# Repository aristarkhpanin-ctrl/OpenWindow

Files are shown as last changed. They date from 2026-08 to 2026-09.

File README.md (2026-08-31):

# OpenWindow — Zigbee-привод открывания окна на проветривание

Проект превращает 3D-печатный реечный привод из папки `pok016/`
в полноценное Zigbee-устройство: окно открывается и закрывается
из Home Assistant, по расписанию, по CO₂ или по датчику дождя.

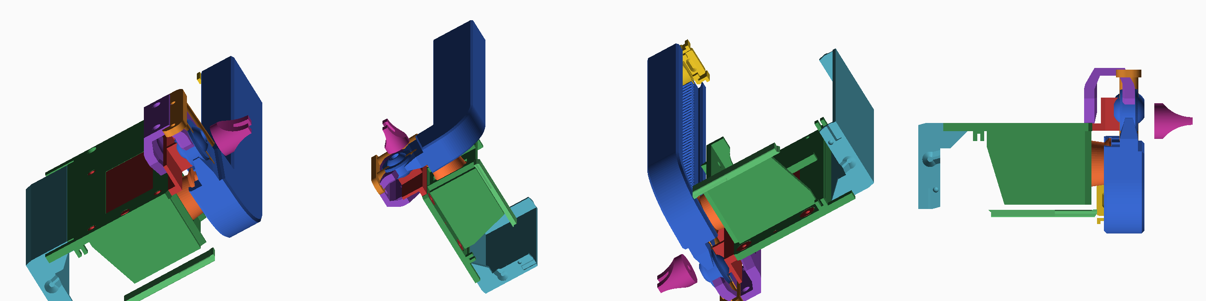
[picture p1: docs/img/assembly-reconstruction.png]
Реконструкция сборки


## Что получится

- Устройство видно в сети как стандартная **штора (Window Covering)** —
  Home Assistant, Zigbee2MQTT и deCONZ понимают его без кастомных описаний.
- Команды: открыть / закрыть / стоп / **позиция в процентах**.
- **Защита от защемления** по току мотора: упёрлись — остановились и отъехали.
- Позиция переживает отключение питания.
- Ручное управление кнопкой на плате.

## С чего начать

Читайте по порядку — документы идут в том порядке, в котором делается работа:

| Документ | О чём |
|---|---|
| [0. С чего начать](docs/00-roadmap.md) | **читайте первым**: порядок работ, чекпоинты, что заказывать сейчас |
| [1. Разбор макетов](docs/01-mechanics.md) | что за механизм в `pok016/`, все обмеры, чего в наборе не хватает |
| [2. Что купить](docs/02-bom.md) | список компонентов, выбор мотора, расчёт момента |
| [3. Печать и сборка](docs/03-print-and-assembly.md) | параметры печати, сборка узлов, установка на окно |
| [4. Электроника](docs/04-electronics.md) | схема, распиновка, монтаж, настройка защиты |
| [5. Прошивка](docs/05-firmware.md) | установка Arduino IDE с нуля, заливка, калибровка |
| [6. Умный дом](docs/06-integration.md) | сопряжение, ZHA/Z2M, готовые автоматизации |

## Коротко о железе

| | |
|---|---|
| Контроллер | ESP32-C6 (Zigbee 3.0 + Wi-Fi + BLE) |
| Драйвер | DRV8871 |
| Мотор | червячный мотор-редуктор 12 В, 20 об/мин, вал ⌀6 мм с лыской |
| Датчик тока | INA219 |
| Питание | 12 В / 3 А |
| Ход | 100 мм, полный цикл ~5 с |
| Бюджет | ≈ 4 000 ₽ вместе с мотором и печатью |

## Главное, что нужно знать до начала

1. **В наборе нет ведущей шестерни.** Нужна отдельная, металлическая:
   модуль 1, z = 18, ширина ≥ 9 мм, посадка ⌀6 мм с лыской. Подробности —
   в [разборе макетов](docs/01-mechanics.md), §1.3.
2. **Редуктор должен быть червячным.** Он самотормозящий, иначе ветер
   и вес створки будут продавливать рейку назад.
3. **Печатайте PETG, не PLA.** Привод стоит у окна и летом греется
   выше температуры размягчения PLA.
4. **Марка мотора из STL не восстанавливается.** Известен посадочный
   интерфейс (4×M3 сеткой 18 × 33 мм, вал ⌀6 с лыской); в
   [BOM](docs/02-bom.md) есть чек-лист проверки перед покупкой.

## Структура репозитория

```
pok016/                            исходные STL (как были загружены)
docs/                              документация
firmware/zigbee_window_opener/     скетч Arduino + config.h
tools/                             скрипты обмера и рендера STL
```

## Инструменты обмера

Все размеры в документации получены скриптами из `tools/` — их можно
перезапустить и проверить:

```bash
pip install numpy
python3 tools/stlinfo.py pok016       # габариты и объёмы
python3 tools/holes.py   pok016       # цилиндрические отверстия и их координаты
python3 tools/render.py  pok016 out/  # изометрии деталей в PNG
```

## Безопасность

Устройство двигает створку с усилием под 200 Н. Не собирайте его
без защиты по току, проверьте траекторию створки и оставьте
возможность отсоединить рейку от окна без инструмента.
Подробно — в [разделе 4](docs/04-electronics.md), §3.5.

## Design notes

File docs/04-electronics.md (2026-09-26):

# 3. Электроника: схема и монтаж

## 3.1. Структура

```
     ┌──────────────┐
     │ БП 12 В / 3 А│
     └──────┬───────┘
            │ 12 В
     ┌──────┴────────┬─────────────────┐
     │               │                 │
┌────┴─────┐   ┌─────┴──────┐   ┌──────┴──────┐
│ MP1584EN │   │  INA219    │   │  DRV8871    │
│ 12В → 5В │   │ (в разрыв  │   │  VM         │
└────┬─────┘   │  плюса     │   │             │
     │ 5 В     │  мотора)   │   │  OUT1 OUT2  │
     │         └─────┬──────┘   └───┬─────┬───┘
┌────┴──────────┐    │              │     │
│  ESP32-C6     │    │          ┌───┴─────┴───┐
│               │◄───┘ I²C      │ Мотор 12 В  │
│ GPIO2  ───────┼───────────────► IN1         │
│ GPIO3  ───────┼───────────────► IN2         │
│ GPIO6  SDA    │               └─────────────┘
│ GPIO7  SCL    │
│ GPIO18 ◄──────┼─── концевик «закрыто»  ─── GND
│ GPIO19 ◄──────┼─── концевик «открыто»  ─── GND
└───────────────┘
```

## 3.2. Таблица соединений

### Питание

| Откуда | Куда | Провод |
|---|---|---|
| БП 12 В «+» | предохранитель 2 А → шина 12 В | 0,5 мм² |
| Шина 12 В | MP1584 `IN+` | 0,5 мм² |
| Шина 12 В | INA219 `VIN+` | 0,5 мм² |
| INA219 `VIN−` | DRV8871 `VM` | 0,5 мм² |
| БП «−» | общая земля GND | 0,5 мм² |
| MP1584 `OUT+` (**5,0 В**) | ESP32-C6 `5V` | 0,2 мм² |
| MP1584 `OUT−` | GND | 0,2 мм² |

> ❗ **MP1584 нужно настроить ДО подключения платы.** Подайте на него 12 В,
> подкрутите подстроечник, добейтесь на выходе **5,0 В по мультиметру**,
> и только потом подключайте ESP32. На модуле «из коробки» может быть
> и 12 В на выходе — это мгновенно убьёт плату.

### Сигналы

| ESP32-C6 | Куда | Примечание |
|---|---|---|
| GPIO2 | DRV8871 `IN1` | ШИМ 20 кГц |
| GPIO3 | DRV8871 `IN2` | ШИМ 20 кГц |
| GPIO6 | INA219 `SDA` | подтяжки есть на модуле |
| GPIO7 | INA219 `SCL` | |
| 3V3 | INA219 `VCC` | датчик питается от 3,3 В |
| GPIO18 | концевик «закрыто», контакт **COM** | второй контакт (**NO**) → GND |
| GPIO19 | концевик «открыто», контакт **COM** | второй контакт (**NO**) → GND |
| GND | общая земля | обязательно одна точка |

Концевики подключаются **нормально-разомкнутыми на замыкание в GND**.
Внутренняя подтяжка включена в прошивке (`INPUT_PULLUP`), внешние резисторы
не нужны. Логика: нажат → LOW → «доехали».

### Мотор

| DRV8871 | Куда |
|---|---|
| `VM` | 12 В (через INA219) |
| `GND` | общая земля |
| `OUT1` | провод мотора A |
| `OUT2` | провод мотора B |

Полярность мотора на этом этапе неважна — если окно поедет не в ту сторону,
поменяйте `#define MOTOR_INVERT 0` на `1` в `config.h`. Это надёжнее,
чем перепаивать.

## 3.3. Обязательные мелочи, о которых легко забыть

1. **Электролит 470 мкФ / 25 В** — прямо на клеммах `VM`/`GND` драйвера.
   Пусковой ток мотора проседает питание, и без этого конденсатора
   ESP32 будет перезагружаться в момент старта. Это самая частая проблема
   в подобных проектах.
2. **0,1 мкФ** на питание INA219 и на 3,3 В ESP32.
3. **Скрутите провода мотора в косичку** — они излучают помехи прямо
   в антенну Zigbee, которая находится в 3 см.
4. **Общая земля одной точкой.** Не соединяйте GND «гирляндой» через модули.
5. Провода мотора и питания — **не ближе 10 мм к антенне** ESP32-C6
   (это торец платы с зигзагом дорожки; его нельзя закрывать металлом).

## 3.4. Настройка порога защиты от защемления

Порог `CURRENT_STALL_A` в `config.h` подбирается **по факту**, на собранном
приводе. Порядок:

1. В скетче поставьте `#define DEBUG_CURRENT 1`, прошейте плату,
   откройте Serial Monitor на 115200. Ток начнёт печататься 5 раз в секунду.
2. Прогоните окно из края в край и запишите **рабочий** ток — обычно 0,3–0,7 А.
3. Придержите створку рукой и посмотрите ток **упора** — обычно 1,5–2,5 А.
4. Поставьте порог **посередине**: например, рабочий 0,6 А, упор 2,0 А → `1.20f`.
5. Верните `#define DEBUG_CURRENT 0`.

Слишком низкий порог → привод будет останавливаться на ровном месте.
Слишком высокий → защемление сработает поздно. Лучше начать с низкого
и поднимать.

## 3.5. Безопасность

Это устройство двигает тяжёлую створку с усилием под 200 Н. Отнеситесь всерьёз:

- **Защита по току обязательна.** Не собирайте без INA219 «на время» —
  временное имеет свойство оставаться навсегда.
- **Не ставьте на окно в детской**, если рядом нет присмотра.
- **Проверьте траекторию створки** — на пути не должно быть штор, цветов, рам.
- **Предохранитель 2 А** на входе — не пропускайте.
- Держите **ручной режим**: рейка должна отсоединяться от створки штифтом M4
  без инструмента, чтобы окно можно было открыть руками при отказе электроники.
- Если корпус нагревается выше ~50 °C при работе — что-то не так, ищите причину.

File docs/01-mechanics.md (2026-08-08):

# 1. Разбор макетов из `pok016/`

Всё ниже — результат прямого обмера STL-файлов (скрипты лежат в `tools/`).
Исходного CAD и инструкции в репозитории нет, поэтому сборка восстановлена
по координатам: детали лежат в одной системе координат, то есть они уже
расставлены «как в сборке», а не по центру нуля.

Реконструкция сборки

## 1.1. Что это за механизм

Это **реечный привод (rack & pinion)** для откидного окна:
электромотор через шестерню двигает зубчатую рейку, рейка упирается в створку
и отжимает её на проветривание. Обратный ход — закрывает.

Ключевой момент, который определяет весь выбор электроники: **рейка Г-образная**.
Прямой зубчатый участок идёт вдоль корпуса, а внизу переходит в изогнутый «крюк»
с проушиной — она шарнирно крепится к створке. За счёт изгиба привод получается
компактным, а створка при этом отходит по дуге.

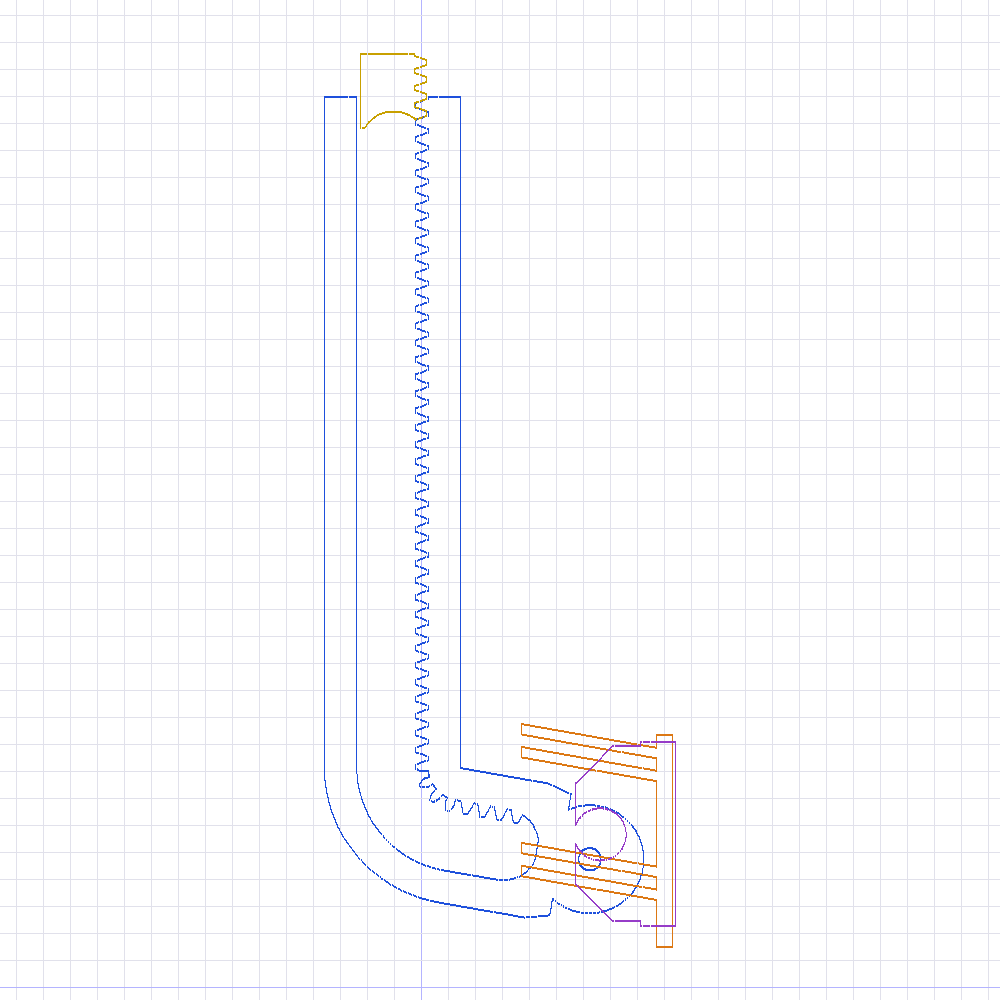
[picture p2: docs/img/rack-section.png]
Сечение рейки


## 1.2. Таблица деталей

| Файл | Габарит, мм | Объём | Назначение |
|---|---|---|---|
| `pok16-openerRack.stl` | 15,8 × 59,2 × 152,0 | 38,8 см³ | Зубчатая рейка с крюком и проушиной |
| `pok16-openerCover.stl` | 70,2 × 37,4 × 97,0 | 34,6 см³ | Корпус целиком (мотор + электроника) |
| `pok16-openerMotoBase.stl` | 58,5 × 32,2 × 93,5 | 16,5 см³ | Рама с площадкой мотора, крепится к раме окна |
| `pok16-openerGuide1.stl` | 55,8 × 13,0 × 67,2 | 10,7 см³ | Г-образный кронштейн-направляющая |
| `pok16-openerLid.stl` | 20,5 × 33,8 × 84,0 | 8,7 см³ | Крышка отсека электроники |
| `pok16-openerFixer.stl` | 20,0 × 22,0 × 34,0 | 6,2 см³ | Кронштейн на створку (ответная часть) |
| `pok16-openerGuide2.stl` | 10,0 × 28,0 × 42,3 | 2,5 см³ | Прижимная направляющая рейки |
| `pok16-openerEndstop.stl` | 14,7 × 19,0 × 13,7 | 1,5 см³ | Ограничитель хода вверху |
| `pok16-openerFixerNut.stl` | 15,0 × 14,0 × 14,0 | 1,2 см³ | Ответная гайка/подложка к Fixer |
| `pok16-openerMotoFix.stl` | ⌀20,5 × 12,8 | 1,05 см³ | Коническая втулка-фиксатор вала |
| `pok016-MotoFix.stl` | ⌀20,5 × 12,8 | 1,05 см³ | То же самое, повёрнуто «под печать» |
| `pok16-openerMasker.stl` | 42,7 × 3,1 × 7,7 | 0,86 см³ | Накладка-заглушка |
| `pok16-openerGearSpacer.stl` | ⌀12 × 4,0 | 0,29 см³ | Дистанционная шайба на вал мотора |
| `pok16-openerMotoFixSuport.stl` | ⌀17,8 × 2,0 | 0,22 см³ | Опорная шайба под втулку |
| `pok16-openerOffTool.stl` | 18,0 × 0,4 × 23,5 | 0,11 см³ | Тонкий «ключ» для ручного расцепления |
| `pok16-openerMotoNut.stl` | ⌀7,3 × 1,2 | 0,04 см³ | Шаблон гнезда под гайку M4 |
| `pok16-openerLid-Insert.stl` | 21,2 × 31,6 × 78,9 | — | Вспомогательный «негатив» отсека электроники |
| `pok16-openerLid-Inset-Open.stl` | 26,1 × 31,6 × 78,9 | — | То же, вариант с проёмом |

Последние две — не печатаемые детали, а булевы заготовки из CAD.
Печатать их не нужно, но они очень полезны: `Lid-Insert` — это ровно тот объём,
который остаётся свободным под плату и провода.

## 1.3. Точные размеры, которые важны для сборки

### Зубчатое зацепление

| Параметр | Значение | Как измерено |
|---|---|---|
| Шаг зубьев | **3,142 мм** | расстояние между вершинами зубьев по STL |
| Модуль | **m = 1** | шаг / π = 3,142 / 3,1416 |
| Высота зуба | 2,25 мм | = 2,25 · m, стандартная пропорция |
| Ширина зуба (венца) | **9,0 мм** | рейка по X: 43,1…52,1 |
| Длина зубчатого участка | ~112 мм | прямая часть по Z: 45…157 |
| Ось шестерни | 9,25 мм от делительной линии рейки | центр отверстия ⌀21 минус линия зуба |

Отсюда шестерня: **модуль 1, z = 18, делительный ⌀18 мм, ширина ≥ 9 мм**.
Межосевое по модели 9,25 мм при теоретических 9,0 — заложено 0,25 мм зазора,
это нормальный люфт для FDM-печати.

> ⚠️ **Шестерни в наборе нет.** Из 18 файлов ни один не является ведущей
> шестернёй. Её нужно либо купить (латунная/стальная m1 z18 с посадкой ⌀6 мм
> под лыску), либо сгенерировать самому — я бы советовал купить металлическую:
> это самая нагруженная деталь привода.

### Вал мотора

`GearSpacer` — шайба ⌀12 × 4 мм с отверстием **⌀6 мм с лыской на 2,24 мм от оси**
(то есть «под ключ» 5,24 мм). Это прямо говорит:

> **вал мотора — ⌀6 мм, D-образный (со срезом).**

### Площадка мотора

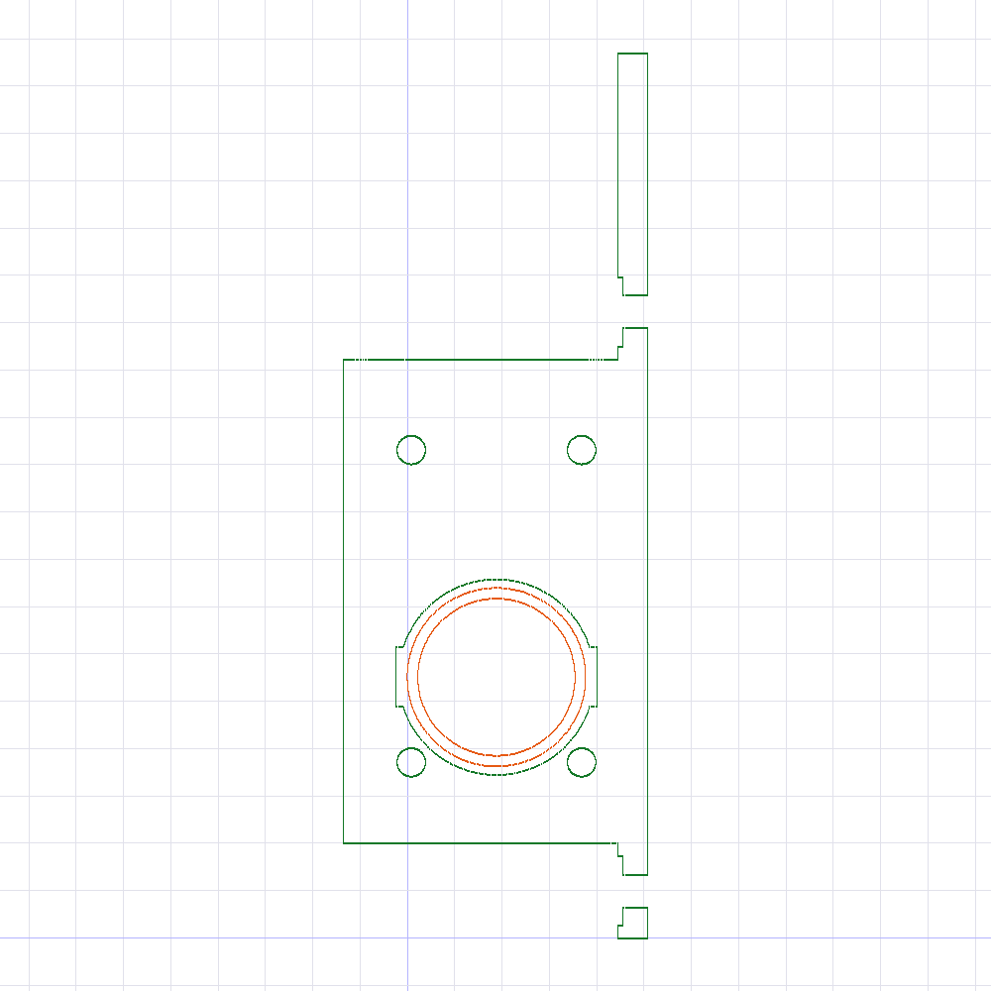
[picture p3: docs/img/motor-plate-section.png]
Сечение площадки мотора


- пластина толщиной 2,4 мм;
- **4 отверстия ⌀3,0 мм (под M3) прямоугольником 18 × 33 мм**;
- центральное отверстие ⌀≈21 мм под выходную втулку/бобышку редуктора;
- ось вала смещена: она на 9 мм ниже центра прямоугольника отверстий.

Это несимметричное расположение — «отпечаток» конкретного мотора.
Смотрите `docs/02-bom.md`, там процедура проверки перед покупкой.

### Крепление к раме окна

Общий для `MotoBase`, `Cover` и `Guide1` шаблон: **4 самореза, сетка 31,5 × 61,2 мм**.
- `MotoBase`: сквозные ⌀3,8 мм с зенковкой ⌀7,5 мм;
- `Guide1`: направляющие ⌀2,5 мм (кондуктор для сверления);
- `Cover`: бобышки ⌀10 мм, сквозь которые проходят те же саморезы.

Под саморез 4 × 30…40 мм по ПВХ-профилю.

### Крепление к створке

`Fixer` + `FixerNut`: два отверстия M3 (⌀3,3 с зенковкой ⌀6,2/6,5) и ось ⌀4,0 мм.
Проушина рейки — ⌀3,79 мм. Значит шарнир — **штифт или винт M4**.

## 1.4. Отсек электроники — сколько у нас места

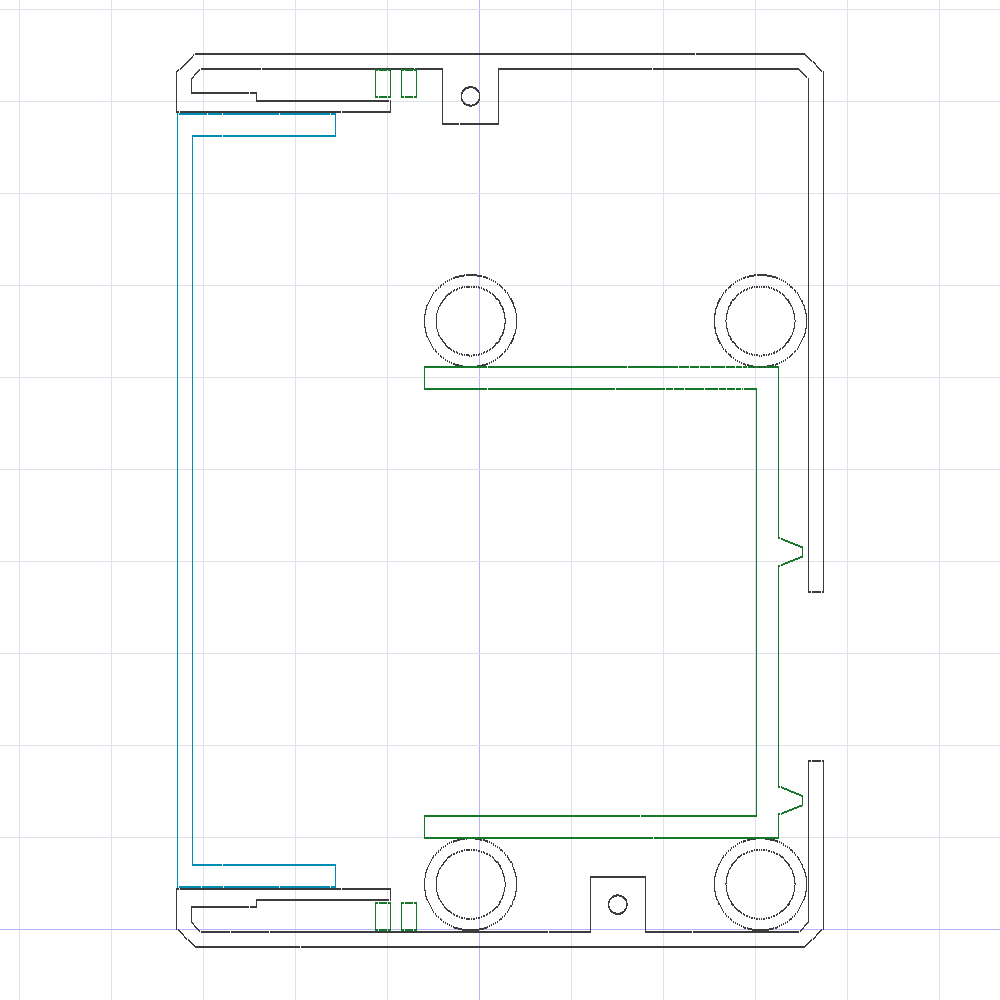
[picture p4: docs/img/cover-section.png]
Сечение корпуса


Свободный объём под крышкой `Lid` (по «негативу» `Lid-Insert`):

> **21,2 × 31,6 × 78,9 мм**

Это ~53 см³. Немало, но узко: 21 мм — жёсткое ограничение по толщине.
Практический вывод для выбора компонентов:

- **влезает**: ESP32-C6 SuperMini (23 × 18 мм), драйвер DRV8871 (20 × 20 мм),
  понижающий модуль MP1584 (22 × 17 мм) — все три «столбиком» по высоте;
- **влезает с натягом**: ESP32-C6-DevKitC-1 (52 × 25,5 мм) — по ширине проходит,
  но USB-разъём придётся выводить наружу;
- **не влезает**: аккумулятор 18650 вместе с платами. Либо банка, либо электроника.

Поэтому базовый вариант в этом проекте — **питание от внешнего блока 12 В**,
а не автономный. Подробности и обоснование — в `docs/04-electronics.md`.

## 1.5. Что осталось неизвестным

Честно перечисляю, чего из STL получить нельзя:

1. **Точная модель мотора.** Известен посадочный интерфейс (4×M3 18×33 мм,
   вал ⌀6 с лыской, бобышка ⌀21), но не марка. Проверочная процедура — в BOM.
2. **Точное число зубьев шестерни** — 18 по расчёту, но допускаю 19 при другом
   расположении оси. Проверяется примеркой: рейка должна ходить без закусывания.
3. **Порядок сборки** от автора. Реконструкция по координатам даёт взаимное
   положение деталей, но не последовательность операций.

## 1.6. Как повторить обмер

```bash
pip install numpy
python3 tools/stlinfo.py pok016            # габариты и объёмы всех деталей
python3 tools/holes.py   pok016            # все цилиндрические отверстия
python3 tools/render.py  pok016 out/       # изометрии каждой детали в PNG
```

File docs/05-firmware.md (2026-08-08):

# 4. Прошивка: от нуля до работающего устройства

Раздел рассчитан на то, что вы **никогда не держали в руках Arduino**.
Каждый шаг — буквальный.

## 4.1. Устанавливаем среду (20 минут)

### Шаг 1. Arduino IDE

Скачайте **Arduino IDE 2.x** с <https://www.arduino.cc/en/software> и установите.

### Шаг 2. Добавляем поддержку ESP32

1. `File` → `Preferences`.
2. В поле **Additional boards manager URLs** вставьте:
   ```
   https://espressif.github.io/arduino-esp32/package_esp32_index.json
   ```
3. `OK`.
4. Слева откройте **Boards Manager** (иконка платы), найдите **esp32 by Espressif Systems**.
5. Установите версию **3.1.0 или новее**. Это важно: Zigbee-библиотека
   появилась именно в 3.1.0. Установка займёт несколько минут — пакет большой.

### Шаг 3. Выбираем плату и режим

`Tools` → и выставьте:

| Параметр | Значение |
|---|---|
| Board | **ESP32C6 Dev Module** |
| **Zigbee mode** | **Zigbee ZCZR (coordinator/router)** |
| **Partition Scheme** | **Zigbee ZCZR 4MB with spiffs** |
| USB CDC On Boot | **Enabled** |
| Erase All Flash Before Sketch Upload | **Enabled** (только в первый раз!) |
| Port | появится после подключения платы по USB |

> Если пункта **Zigbee mode** нет — у вас старая версия ядра, вернитесь к шагу 2.
> Если не выставить Partition Scheme, прошивка соберётся, но Zigbee-стек
> не стартует: ему нужен отдельный раздел под сетевые ключи.

### Шаг 4. Открываем скетч

`File` → `Open` → выберите
`firmware/zigbee_window_opener/zigbee_window_opener.ino`.
Файл `config.h` подтянется автоматически и появится второй вкладкой.

## 4.2. Первая прошивка — на столе, без мотора

**Не подключайте мотор к первой прошивке.** Сначала убедимся, что
устройство входит в сеть.

1. Подключите ESP32-C6 к компьютеру по USB-C.
2. Нажмите **Upload** (стрелка вправо).
3. Если не прошивается — зажмите **BOOT**, коротко нажмите **RESET**,
   отпустите BOOT, повторите Upload.
4. Откройте `Tools` → **Serial Monitor**, скорость **115200**.

Вы должны увидеть:

```
=== OpenWindow — Zigbee window opener ===
[INA219] НЕ найден — защита по току отключена
[NVS] полный ход 9000 мс, позиция 100%
[ZB] запуск стека…
[ZB] подключение к сети....
```

Точки будут идти, пока устройство не вступит в сеть — это нормально.
Переходите к `docs/06-integration.md`, добавьте устройство в сеть,
и точки сменятся на `готово`.

## 4.3. Что делает прошивка

### Модель устройства

Устройство объявляет себя как **Window Covering** (кластер ZCL `0x0102`,
тип `AWNING`). Это даёт «бесплатно»:

- команды `Open`, `Close`, `Stop`, `Go to Lift Percentage`;
- атрибут текущей позиции, который координатор опрашивает и показывает;
- готовую сущность `cover.*` в Home Assistant с ползунком.

> **Про проценты.** В стандарте Zigbee `0 % = открыто`, `100 % = закрыто`.
> В Home Assistant у штор наоборот. Пересчёт делает координатор, вам
> ничего править не нужно — просто не пугайтесь, увидев в логах «100 %»
> у закрытого окна.

### Как считается позиция

Энкодера нет, поэтому позиция считается **по времени**:

1. При калибровке привод едет до упора «закрыто», потом до упора «открыто»
   и засекает длительность полного хода → `travelMs`.
2. `travelMs` сохраняется в NVS (переживает перезагрузку и отключение питания).
3. Во время движения позиция интегрируется по времени.
4. **Приезд в крайние положения обнуляет накопленную ошибку** — концевик
   важнее расчёта. Поэтому дрейф не накапливается: каждое полное
   открытие/закрытие «сбрасывает» счётчик.

Это классический подход для приводов штор, точность — единицы процентов.
Если нужна точность лучше — ставьте мотор с энкодером (см. `docs/02-bom.md`).

### Защита от защемления

Каждые 5 мс читается ток мотора через INA219. Если ток держится выше
`CURRENT_STALL_A` дольше `STALL_CONFIRM_MS` (250 мс):

1. мотор останавливается;
2. **отъезжает назад** на `BACKOFF_MS` (700 мс), освобождая зажатое;
3. устройство переходит в состояние `ST_FAULT`, светодиод краснеет;
4. позиция пересчитывается и отправляется координатору.

Первые `INRUSH_IGNORE_MS` (600 мс) после старта ток игнорируется —
пусковой бросок в 2–3 раза выше рабочего и иначе давал бы ложные срабатывания.

### Плавный пуск и торможение

Функция `rampedDuty()` разгоняет ШИМ за 350 мс и снижает его на подходе
к цели. Это заметно продлевает жизнь пластиковой рейке: удар зубьев
на полном моменте — главная причина их срезания.

## 4.4. Калибровка

Обязательна после сборки механики.

1. Убедитесь, что створка свободна и на пути ничего нет.
2. **Зажмите кнопку BOOT на 3–10 секунд**, отпустите.
3. Привод поедет закрываться до упора, потом откроется до упора.
4. В Serial Monitor появится:
   ```
   [CAL] полный ход = 6420 мс, сохранено
   ```
5. Всё, значение записано навсегда (до следующей калибровки).

### Все функции кнопки BOOT

| Нажатие | Действие |
|---|---|
| Короткое (< 3 с) | открыть, если закрыто; закрыть, если открыто; стоп во время движения |
| 3–10 с | калибровка |
| Дольше 10 с | сброс к заводским, выход из Zigbee-сети |

### Светодиод

| Цвет | Значение |
|---|---|
| Мигает жёлтым | ищет сеть |
| Тускло-зелёный | в сети, стоит |
| Синий | едет |
| Красный | сработала защита (`ST_FAULT`) |
| Фиолетовый | идёт сброс к заводским |

## 4.5. Настройка под свою механику

Всё в `config.h`:

| Параметр | Когда менять |
|---|---|
| `MOTOR_INVERT` | окно едет в обратную сторону |
| `CURRENT_STALL_A` | подбор порога защиты — см. `docs/04-electronics.md` |
| `DUTY_RUN` | мотор слишком быстрый/медленный (900 из 1023) |
| `RAMP_MS` | резкий старт, стучат зубья |
| `USE_LIMIT_SWITCHES` | поставьте `0`, если собрали без концевиков |
| `USE_INA219` | поставьте `0`, если собрали без датчика тока (**не советую**) |
| `ZB_ROLE` | `ZIGBEE_END_DEVICE` при питании от батареи |

## 4.6. Типичные проблемы

| Симптом | Причина | Что делать |
|---|---|---|
| `[ZB] стек не стартовал` | не выбран Partition Scheme | `Tools` → `Zigbee ZCZR 4MB with spiffs` |
| Точки идут вечно | сеть не открыта для сопряжения | откройте сеть в HA/Z2M на 4 минуты |
| ESP32 перезагружается при старте мотора | нет конденсатора 470 мкФ | впаяйте его на `VM`/`GND` драйвера |
| `[INA219] НЕ найден` | перепутаны SDA/SCL или нет питания | проверьте GPIO6/GPIO7 и 3,3 В |
| Позиция «уплывает» | не сделана калибровка | зажмите BOOT на 3 с |
| Защита срабатывает постоянно | порог занижен | поднимите `CURRENT_STALL_A` |
| Устройство пропадает из сети | помехи от проводов мотора | скрутите их в косичку, отодвиньте от антенны |

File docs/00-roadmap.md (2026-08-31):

# 0. С чего начать и в каком порядке

Документ для ситуации «купил детали, открыл десять вкладок и перестал
понимать, что делать». Читайте его первым.

## 0.1. Это две независимые задачи, а не одна

Половина путаницы возникает оттого, что их обсуждают вперемешку.

| | Задача А — «мозг» | Задача Б — «устройство» |
|---|---|---|
| Что это | координатор + Home Assistant | привод на окно |
| Из чего | USB-свисток, мини-ПК/Raspberry Pi | печать, мотор, ESP32-C6 |
| Зачем | вообще для умного дома | конкретно для проветривания |
| Бюджет | 10 000–15 000 ₽ (один раз на всю квартиру) | ~4 000 ₽ |

Задача А делается **один раз** и потом обслуживает все будущие устройства.
Задача Б повторяется для каждого окна.

**Их можно делать параллельно.** Печатать детали и ждать мотор с
маркетплейса можно, пока разбираетесь с Home Assistant.

## 0.2. Порядок работ

Каждый шаг заканчивается проверкой. Не переходите дальше, пока
предыдущая проверка не пройдена — иначе при поломке будет непонятно,
что именно сломалось.

### Шаг 1. Home Assistant на обычном компьютере — 1 вечер, 0 ₽

Поставьте HA в VirtualBox или Docker на свой ноутбук/ПК.
Официальная инструкция: <https://www.home-assistant.io/installation/>

Цель шага — не «сделать умный дом», а **посмотреть, как это выглядит**.
Пощёлкайте интерфейс, создайте тестовую автоматизацию.

> ✅ **Проверка:** HA открывается в браузере по адресу `homeassistant.local:8123`,
> вы создали учётку и видите пустой дашборд.

После этого шага все дальнейшие решения станут понятными сами собой.

### Шаг 2. Решить, где HA будет жить постоянно — 1 заказ

Ноутбук для этого не годится: хаб должен работать 24/7 и переживать
перезагрузки. Варианты по возрастанию удобства:

| Вариант | Цена | Комментарий |
|---|---|---|
| **Б/у мини-ПК x86** (Lenovo ThinkCentre Tiny, Dell OptiPlex Micro) | 8 000–12 000 ₽ | **рекомендую**: SSD вместо SD-карты, x86 — никаких плясок с ядрами, запас мощности навсегда |
| Raspberry Pi 4/5 + SSD | 8 000–14 000 ₽ | классика, но **обязательно с SSD**: SD-карты в хабах умирают за год-два |
| Home Assistant Green | ~15 000 ₽ | готовая коробка «включил и работает», ноль настройки |

**Старые ТВ-приставки (MXIII, Tanix и подобные) — не вариант.** Не из-за
мощности. У 32-битных (armhf) Home Assistant просто не ставится штатно,
а у 64-битных вроде S905W2 проблема в другом: под них нет поддерживаемых
сборок Linux, и вы будете месяцами подбирать DTB и ловить зависания.
Хаб — это то, от чего зависит свет в квартире; экономия 6 000 ₽ здесь
оплачивается вечерами отладки и последующей ненадёжностью.

> ✅ **Проверка:** HA работает на отдельной железке, вы выключили ноутбук,
> и он продолжает работать.

### Шаг 3. Развилка: Zigbee или Wi-Fi

Решайте **только после шага 1**, когда увидите HA своими глазами.

| | Zigbee | Wi-Fi (ESPHome) |
|---|---|---|
| Нужен координатор | да, ~2 500 ₽ | **нет** |
| Сложность старта | средняя | **низкая** |
| Батарейные датчики | да | нет |
| Нагрузка на Wi-Fi | нет | растёт с числом устройств |
| Когда выигрывает | от ~10 устройств | 1–5 устройств |

**Если этот привод — ваше первое устройство в умном доме, начните с Wi-Fi.**
Ниже порог входа, меньше деталей, меньше мест для ошибки. Zigbee всегда
можно добавить позже — HA работает с обоими одновременно.

**Если Zigbee-устройства уже есть или точно планируются десятками** —
берите Zigbee сразу, чтобы не переделывать.

Прошивка в этом репозитории написана под Zigbee. Вариант под ESPHome
делается из того же железа, меняется только прошивка.

### Шаг 4. Координатор — только если выбрали Zigbee

- **Sonoff ZBDongle-P** (чип CC2652P) — самый универсальный, работает
  и с ZHA, и с Zigbee2MQTT. ~2 500 ₽.
- **Обязательно USB-удлинитель 0,5–1 м.** Не «желательно», а обязательно.
  Воткнутый напрямую свисток ловит помехи от USB 3.0 и HDMI на тех же
  2,4 ГГц — это причина примерно половины жалоб «Zigbee глючит».
- Ставьте хаб ближе к центру квартиры, не в щиток и не за телевизор.
- Разведите каналы с Wi-Fi: Wi-Fi на 1/6/11, Zigbee на 15, 20 или 25.

> ✅ **Проверка:** в HA добавлена интеграция ZHA, свисток определился.

### Шаг 5. Электроника на столе — до всякой механики

Закажите электронику по [BOM](02-bom.md), §2.1 и соберите **на столе,
без мотора и без окна**:

1. ESP32-C6 подключён по USB к компьютеру;
2. прошит скетч из `firmware/`;
3. устройство вошло в сеть и видно в Home Assistant.

Подробно — [раздел 5](05-firmware.md), §5.2.

> ✅ **Проверка:** в HA появилась сущность `cover.openwindow_pok16`,
> кнопки нажимаются, в Serial Monitor видны сообщения.

Это самый важный чекпоинт проекта. После него вы точно знаете, что
софт и радио работают, и все дальнейшие проблемы — механические.

### Шаг 6. Печать и механика

Параллельно с шагами 1–5, потому что печать долгая, а мотор ехать будет
неделями. См. [раздел 3](03-print-and-assembly.md).

Соберите механику **на столе**, прокрутите рукой из края в край.

> ✅ **Проверка:** рейка ходит плавно, зубья не закусывают,
> шарнир M4 свободно вращается.

### Шаг 7. Сводим вместе

Подключаете мотор к драйверу, питание 12 В, калибруете (BOOT на 3 с),
подбираете порог защиты по току ([раздел 4](04-electronics.md), §3.4).
Всё ещё **на столе**.

> ✅ **Проверка:** привод ездит по команде из HA, придержали рейку рукой —
> остановился и отъехал назад.

### Шаг 8. Установка на окно

Только теперь сверлим раму. См. [раздел 3](03-print-and-assembly.md), §3.5.

## 0.3. Что заказывать прямо сейчас

Если хочется уже что-то заказать, чтобы ехало:

**Заказ 1 (едет долго, заказывайте сразу):**
- червячный мотор-редуктор 12 В, 20 об/мин, вал ⌀6 мм с лыской — см. чек-лист в [BOM](02-bom.md), §2.2;
- шестерня m1 z18, ⌀6 с лыской, металлическая;
- ESP32-C6 SuperMini;
- DRV8871, INA219, MP1584EN.

**Заказ 2 (после шага 3, когда решите Zigbee/Wi-Fi):**
- координатор + USB-удлинитель — только для Zigbee;
- мини-ПК под HA.

**Пруток PETG** — если у вас есть принтер, купите сразу, печать долгая.

## 0.4. Если совсем застряли

Правило: **не решайте две проблемы одновременно.** Если что-то не работает,
вернитесь к последнему пройденному чекпоинту и двигайтесь по одному шагу.

Порядок диагностики всегда один:

1. Питание есть? (мультиметр, а не «вроде горит светодиод»)
2. Плата отвечает? (Serial Monitor на 115200)
3. В сети? (`[ZB] ... готово` в логе)
4. Видно в HA?
5. И только потом — механика.

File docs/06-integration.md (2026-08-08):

# 6. Подключение к умному дому

## 6.1. Что нужно со стороны координатора

Zigbee-устройству нужен **координатор** — это не роутер Wi-Fi, а отдельный
USB-стик или Ethernet-шлюз. Если у вас его ещё нет:

| Вариант | Комментарий |
|---|---|
| **SONOFF ZBDongle-E** (EFR32MG21) | лучший выбор по цене/качеству, ~2 000 ₽ |
| SLZB-06 (Ethernet/PoE) | ставится вдали от компьютера, меньше помех |
| ConBee III | хорошая альтернатива |
| Встроенный в SkyConnect / Home Assistant Yellow | если уже есть — используйте |

Дальше — два пути. Оба рабочих, выбирайте под свою систему.

## 6.2. Путь A: Home Assistant + ZHA (проще)

ZHA — встроенная в Home Assistant поддержка Zigbee. Наше устройство
использует **стандартный кластер Window Covering**, поэтому ZHA распознаёт
его автоматически, без кастомных описаний.

1. Home Assistant → **Настройки** → **Устройства и службы** → **Добавить интеграцию** → **Zigbee Home Automation**.
2. Выберите свой стик, дождитесь запуска.
3. Нажмите **Добавить устройство** — сеть откроется на 4 минуты (**Permit join**).
4. Подайте питание на привод (или нажмите RESET).
5. В Serial Monitor должно появиться:
   ```
   [ZB] подключение к сети... готово
   ```
6. В HA появится новое устройство `DIY OpenWindow-pok16` и сущность
   **`cover.openwindow_pok16`**.

Всё. В интерфейсе будут кнопки ▲ ■ ▼ и ползунок позиции.

## 6.3. Путь B: Zigbee2MQTT

Z2M тоже понимает стандартный Window Covering, но для красивых имён
и иконки стоит добавить внешнее описание.

1. Откройте Z2M → **Settings** → **Permit join** → **All**.
2. Подайте питание на привод.
3. Устройство появится как `DIY OpenWindow-pok16`.

Если Z2M пометит его как **Unsupported**, создайте файл
`data/external_converters/openwindow.js`:

```js
const {windowCovering} = require('zigbee-herdsman-converters/lib/modernExtend');

module.exports = [{
    zigbeeModel: ['OpenWindow-pok16'],
    model: 'OpenWindow-pok16',
    vendor: 'DIY',
    description: 'Привод открывания окна на проветривание',
    extend: [windowCovering({controls: ['lift'], coverMode: true})],
}];
```

и перезапустите Zigbee2MQTT.

## 6.4. Проверка после сопряжения

Прогоните по списку, не переходя к автоматизациям:

- [ ] нажатие **▲ (открыть)** открывает окно, не закрывает;
      если наоборот — `MOTOR_INVERT 1` в `config.h`;
- [ ] нажатие **■ (стоп)** останавливает створку в середине хода;
- [ ] ползунок на 50 % ставит створку примерно посередине;
- [ ] позиция в HA обновляется **во время** движения, а не только в конце;
- [ ] после `Reload` страницы позиция сохраняется;
- [ ] придержали створку рукой → привод остановился и отъехал назад;
- [ ] выключили и включили питание → позиция не потерялась.

## 6.5. Автоматизации

### Проветривание по CO₂

Самый осмысленный сценарий, ради которого всё и делается:

```yaml
automation:
  - alias: "Проветривание по CO2"
    trigger:
      - platform: numeric_state
        entity_id: sensor.co2_spalnya
        above: 1000
        for: "00:05:00"
    condition:
      - condition: numeric_state
        entity_id: sensor.temperatura_ulica
        above: 5            # не морозим квартиру
    action:
      - service: cover.set_cover_position
        target: {entity_id: cover.openwindow_pok16}
        data: {position: 40}

  - alias: "Закрыть после проветривания"
    trigger:
      - platform: numeric_state
        entity_id: sensor.co2_spalnya
        below: 700
    action:
      - service: cover.close_cover
        target: {entity_id: cover.openwindow_pok16}
```

### Аварийное закрытие

Обязательный сценарий. Окно, открытое во время дождя или отъезда, —
это испорченный пол и мокрый подоконник.

```yaml
  - alias: "Закрыть окно при дожде или уходе"
    trigger:
      - platform: state
        entity_id: binary_sensor.datchik_dozhdya
        to: "on"
      - platform: state
        entity_id: group.family
        to: "not_home"
      - platform: numeric_state
        entity_id: sensor.skorost_vetra
        above: 8
    action:
      - service: cover.close_cover
        target: {entity_id: cover.openwindow_pok16}
```

### Проветривание по расписанию

```yaml
  - alias: "Утреннее проветривание"
    trigger:
      - platform: time
        at: "07:30:00"
    condition:
      - condition: numeric_state
        entity_id: sensor.temperatura_ulica
        above: 0
    action:
      - service: cover.set_cover_position
        target: {entity_id: cover.openwindow_pok16}
        data: {position: 60}
      - delay: "00:15:00"
      - service: cover.close_cover
        target: {entity_id: cover.openwindow_pok16}
```

## 6.6. Диагностика сети

| Симптом | Причина | Решение |
|---|---|---|
| Устройство не находится | сеть не открыта | Permit join на 4 минуты |
| Находится, но сразу отваливается | помехи от проводов мотора | скрутить провода, отодвинуть от антенны |
| Долгий отклик, «залипание» | далеко от координатора | добавить Zigbee-роутер (любая розетка) между ними |
| Отваливается при работе мотора | просадка питания | конденсатор 470 мкФ на `VM` драйвера |
| Пропадает после перезагрузки HA | устройство ушло из сети | зажать BOOT 10 с, спарить заново |

**Про Wi-Fi.** Zigbee и Wi-Fi делят диапазон 2,4 ГГц. Если сеть работает
нестабильно, разведите каналы: Wi-Fi на канал 1, Zigbee на 25 или 26.
Это настраивается в ZHA/Z2M и в роутере.

## 6.7. Куда развивать дальше

1. **Мотор с энкодером** — точная позиция вместо расчёта по времени.
2. **Датчик SHT40** на I²C и второй Zigbee-эндпоинт `ZigbeeTempSensor` —
   привод сам сообщает температуру и влажность в комнате.
3. **Геркон** на створке — независимое подтверждение «окно закрыто»
   как отдельный `ZigbeeContactSwitch`.
4. **OTA-обновление** — `zbCover.addOTAClient(...)`, прошивка по воздуху
   без снятия привода с окна.
5. **Второе окно** — вся конструкция масштабируется, координатор один.

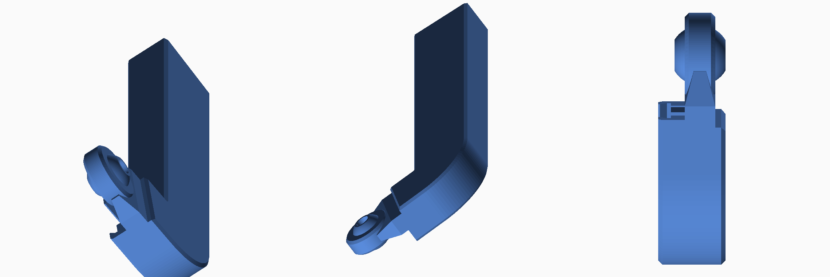
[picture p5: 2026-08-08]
docs/img/part-rack.png

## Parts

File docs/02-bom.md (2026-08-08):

# 2. Что купить (BOM)

Цены ориентировочные, по состоянию на 2026 год, для маркетплейсов/AliExpress.

## 2.1. Электроника

| Поз. | Компонент | Кол-во | Зачем | ≈ цена |
|---|---|---|---|---|
| 1 | **ESP32-C6 SuperMini** (или ESP32-C6-DevKitC-1) | 1 | мозг + Zigbee-радио | 400–900 ₽ |
| 2 | **Драйвер мотора DRV8871** (модуль) | 1 | H-мост, 3,6 А пик | 250 ₽ |
| 3 | **INA219** (модуль GY-219) | 1 | измерение тока → защита от защемления | 200 ₽ |
| 4 | **DC-DC MP1584EN** (регулируемый) | 1 | 12 В → 5 В для платы | 120 ₽ |
| 5 | **БП 12 В / 3 А** с разъёмом 5,5×2,1 | 1 | питание | 600 ₽ |
| 6 | Гнездо питания 5,5×2,1 (панельное) | 1 | | 60 ₽ |
| 7 | Микропереключатель **SS-5GL** (концевик) | 2 | крайние положения | 100 ₽ |
| 8 | Электролит 470 мкФ / 25 В | 1 | сглаживание при пуске мотора | 40 ₽ |
| 9 | Керамика 0,1 мкФ | 2 | развязка по питанию | 10 ₽ |
| 10 | Самовосстанавливающийся предохранитель 2 А | 1 | защита БП | 30 ₽ |
| 11 | Провод ПВС/МГТФ 0,5 мм², термоусадка, разъёмы JST-XH | — | монтаж | 300 ₽ |

**Итого электроники: ≈ 2 100–2 600 ₽.**

### Почему именно ESP32-C6

- Zigbee 3.0 «из коробки» + Wi-Fi + BLE в одном чипе.
- Прошивается через USB-C без программатора — для первого проекта это решающе.
- В ядре `arduino-esp32` 3.1+ есть готовый класс `ZigbeeWindowCovering`, который
  сразу даёт стандартный кластер Window Covering. Home Assistant увидит
  устройство как штору без единой строчки кастомного конвертера.

Альтернатива — ESP32-H2 (тот же API, меньше потребление, но нет Wi-Fi,
а он удобен для отладки). CC2652/nRF52840 дают лучшее радио, но там
совершенно другой уровень входа — для первого проекта не советую.

### Почему DRV8871, а не L298N

L298N — старая биполярная микросхема, роняет ~2 В на каждом плече и греется.
На 12 В мотора это ощутимая потеря и лишний нагрев в закрытом корпусе.
DRV8871 — MOSFET-мост, падение в десятки милливольт, есть встроенная
токовая отсечка и защита от перегрева. Разница в цене — 100 ₽.

## 2.2. Мотор — главный компонент

Из макетов однозначно следует посадочный интерфейс:

- **вал ⌀6 мм с лыской** (D-образный);
- **4 отверстия M3 прямоугольником 18 × 33 мм**;
- центральная бобышка редуктора **⌀ до 21 мм**;
- ось вала на **9 мм ниже** центра прямоугольника крепежа.

### Требования по механике

Ход рейки 100 мм, делительный диаметр шестерни 18 мм → на полный ход
нужно **1,77 оборота** вала.

| Параметр | Нужно | Почему |
|---|---|---|
| Напряжение | 12 В | согласовано с БП и драйвером |
| Обороты | **15–30 об/мин** | полный ход за 3,5–7 с |
| Момент | **1,5–2,5 Н·м** (15–25 кг·см) | усилие на рейке 170–280 Н |
| Тип редуктора | **червячный** | ⚠️ обязательно, см. ниже |
| Ток холостого хода | 0,1–0,3 А | |
| Ток стопорения | до 2,5 А | укладывается в DRV8871 |

### ⚠️ Червячный редуктор — не опция, а требование

Червячная передача **самотормозящая**: усилие со стороны створки не может
провернуть мотор назад. Без этого свойства:

- ветер будет доводить/захлопывать окно;
- вес створки будет продавливать рейку;
- удерживать позицию придётся подачей тока на мотор постоянно.

Планетарный или прямозубый редуктор здесь **не подойдёт**.

### Конкретный кандидат

**JGY-370, 12 В, 20 об/мин** — червячный мотор-редуктор с валом ⌀6 мм с лыской,
крепление 4×M3. Стоит 900–1 500 ₽.

> Я не могу гарантировать совпадение по крепежу на 100 %: марки мотора в файлах
> нет, а у JGY-370 бывают разные корпуса редуктора. **Проверьте перед покупкой
> по фото в объявлении:**
>
> 1. вал — ⌀6 мм и есть срез (лыска);
> 2. на торце редуктора 4 резьбовых отверстия M3;
> 3. расстояния между ними — 18 мм и 33 мм;
> 4. выходная бобышка вокруг вала — не толще ⌀21 мм;
> 5. вал смещён от центра площадки крепежа, а не по центру.

Если пункт 3 не сходится — не страшно: площадка `MotoBase` плоская,
рассверлить 4 новых отверстия под свой мотор проще всего. Главное — сохранить
**положение оси вала**, иначе шестерня не сядет в зацепление с рейкой.

## 2.3. Шестерня

**Её нет в наборе — покупаем отдельно.**

| Параметр | Значение |
|---|---|
| Модуль | 1 |
| Зубьев | 18 (делительный ⌀18 мм) |
| Ширина венца | ≥ 9 мм |
| Посадка | ⌀6 мм с лыской, стопорный винт M3 |
| Материал | **латунь или сталь** |

Печатать её из PLA не советую: это самое нагруженное место, зубья модуля 1
на 9 мм ширины при 200 Н сминаются. Металлическая шестерня m1 z18 стоит 200–400 ₽.

Если найти z18 не выходит — z19 (⌀19 мм) тоже встанет, зацепление будет
чуть плотнее; z20 уже начнёт закусывать.

## 2.4. Печать и крепёж

| Поз. | Что | Кол-во |
|---|---|---|
| 1 | Пруток **PETG** (не PLA!) | ~120 г |
| 2 | Саморез 4 × 35 мм по ПВХ | 4 |
| 3 | Винт M3 × 12 + гайка M3 | 6 |
| 4 | Винт M4 × 25 + гайка M4 (ось шарнира) | 1 |
| 5 | Латунные вставки M3 (термо) | 4 (опционально) |

**Почему PETG.** Привод стоит у окна: летом на солнце корпус греется
до 55–60 °C, а PLA начинает «плыть» уже с 55 °C. PETG держит 75–80 °C
и заметно вязче — важно для зубьев рейки. ABS/ASA ещё лучше по теплу,
но их сложнее печатать новичку.

**Параметры печати рейки** (самая ответственная деталь):
- слой 0,15 мм, периметров 4, заполнение 40 % gyroid;
- ориентация: зубчатой полосой **вертикально**, чтобы слои шли поперёк нагрузки;
- поддержки — только под крюком.

## 2.5. Опционально, для следующих версий

| Компонент | Что даёт |
|---|---|
| Мотор с **энкодером** (JGY-370 бывают с холлами) | точная позиция вместо расчёта по времени |
| Датчик **SHT40** (I²C) | температура/влажность → автопроветривание по датчику |
| **Геркон + магнит** | независимое подтверждение «окно закрыто» |
| Датчик дождя | автозакрытие |

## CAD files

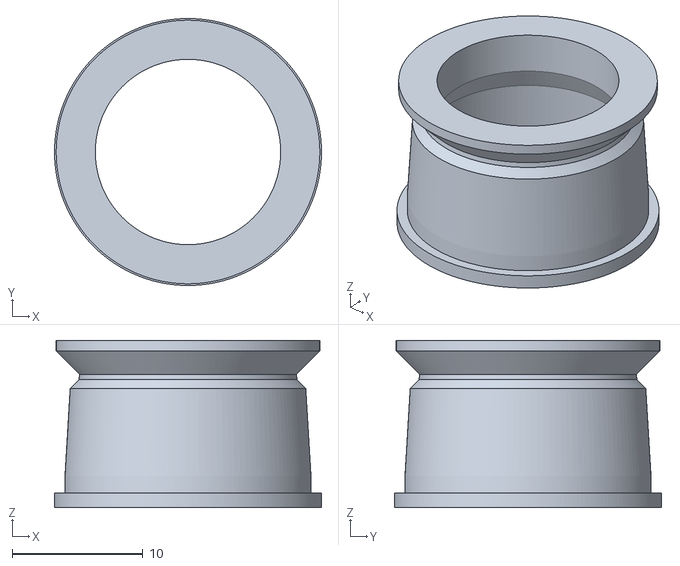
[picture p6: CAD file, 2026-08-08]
pok016/pok016-MotoFix.stl
20.5 x 20.5 x 12.8

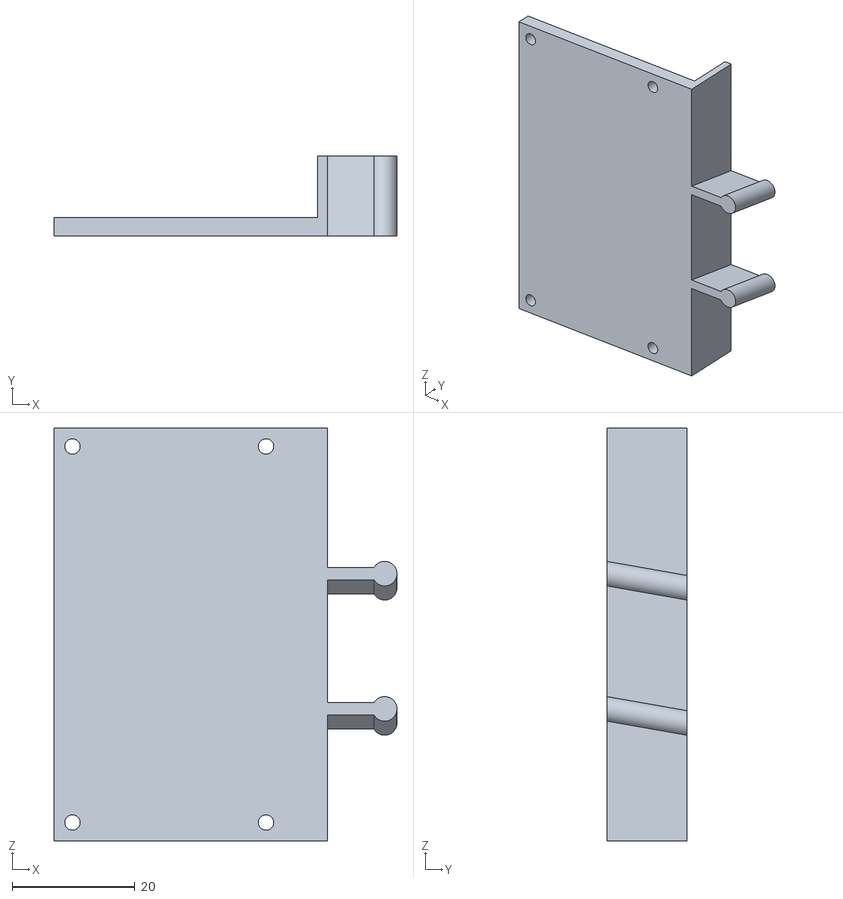
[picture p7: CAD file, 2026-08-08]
pok016/pok16-openerGuide1.stl
55.8 x 13.0 x 67.2

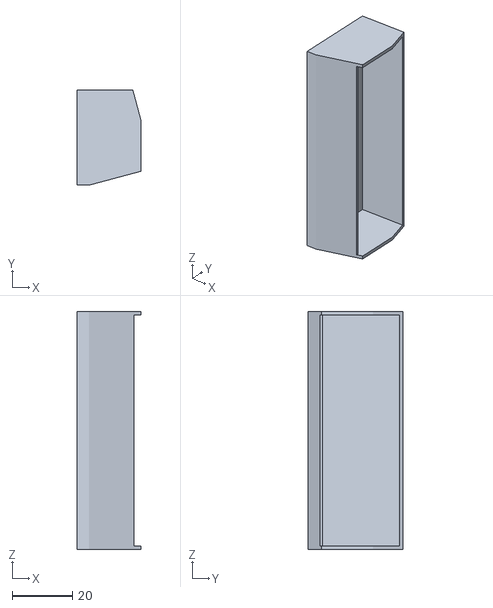
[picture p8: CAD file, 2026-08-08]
pok016/pok16-openerLid-Insert.stl
21.2 x 31.6 x 78.9

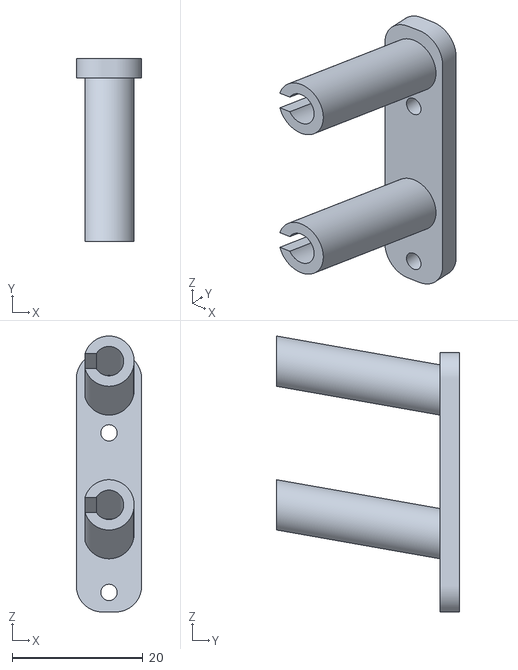
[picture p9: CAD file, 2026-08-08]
pok016/pok16-openerGuide2.stl
10.0 x 28.0 x 42.3

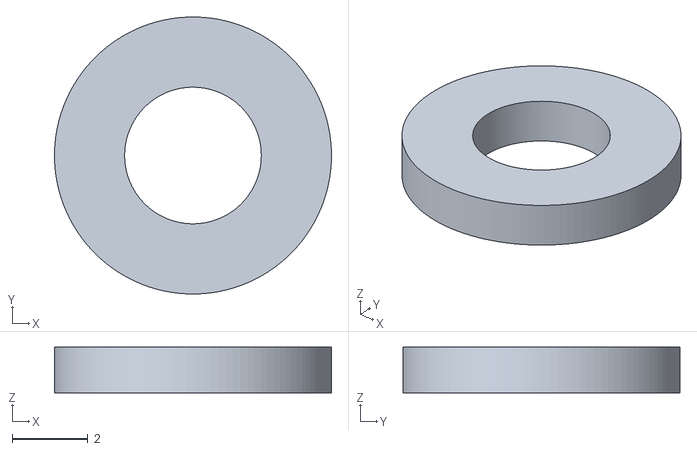
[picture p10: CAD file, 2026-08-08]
pok016/pok16-openerMotoNut.stl
7.30 x 7.30 x 1.20

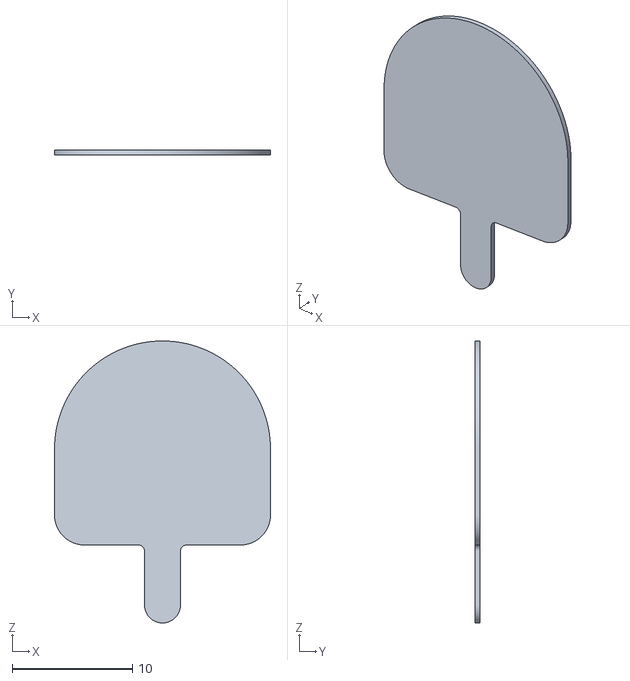
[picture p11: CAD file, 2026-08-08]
pok016/pok16-openerOffTool.stl
18.0 x 0.4 x 23.5

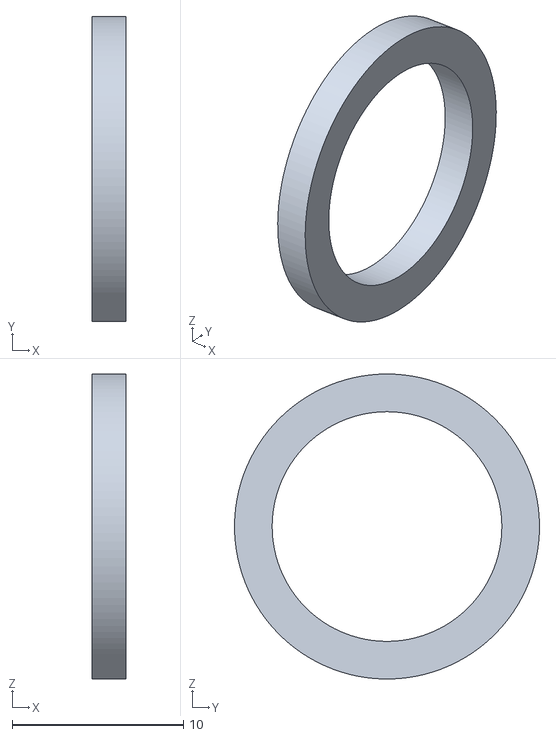
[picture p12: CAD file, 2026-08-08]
pok016/pok16-openerMotoFixSuport.stl
2.00 x 17.8 x 17.8

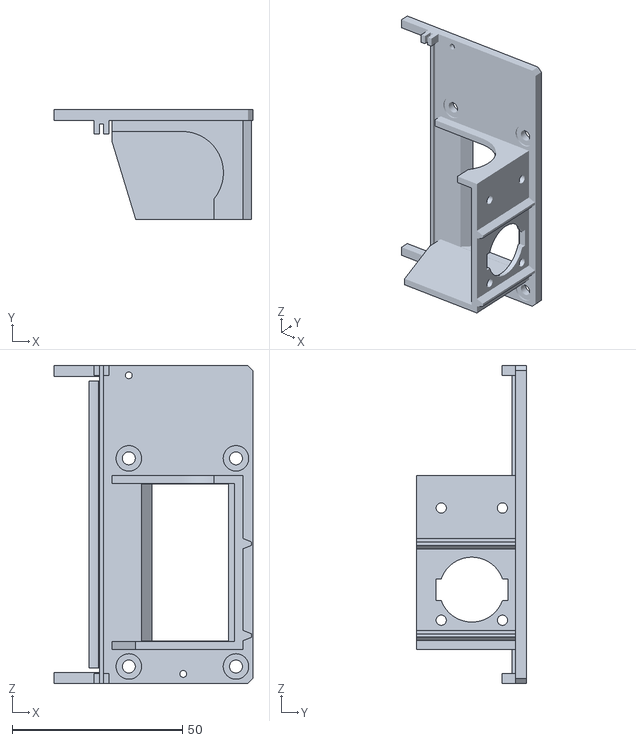
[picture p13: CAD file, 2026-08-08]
pok016/pok16-openerMotoBase.stl
58.5 x 32.2 x 93.5

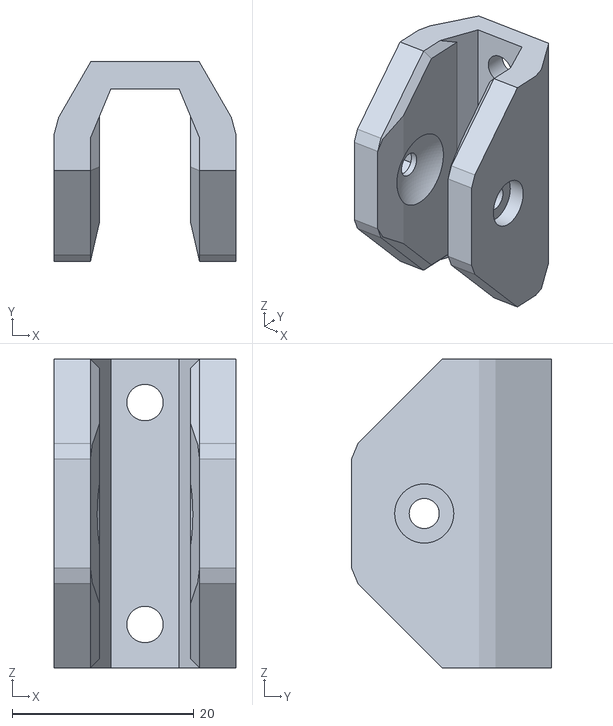
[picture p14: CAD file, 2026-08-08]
pok016/pok16-openerFixer.stl
20.0 x 22.0 x 34.0

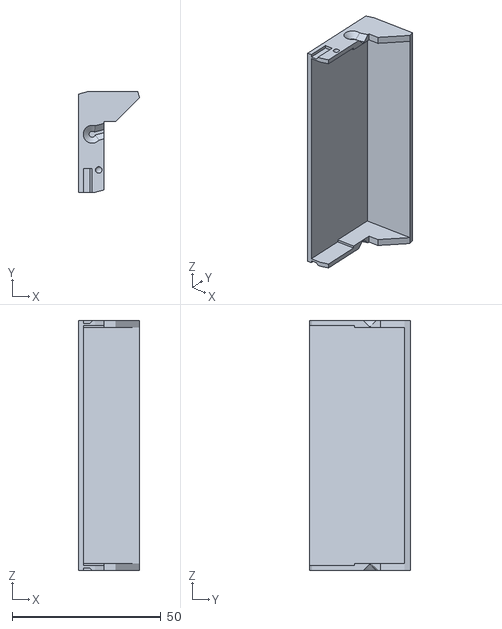
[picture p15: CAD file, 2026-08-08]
pok016/pok16-openerLid.stl
20.5 x 33.8 x 84.0

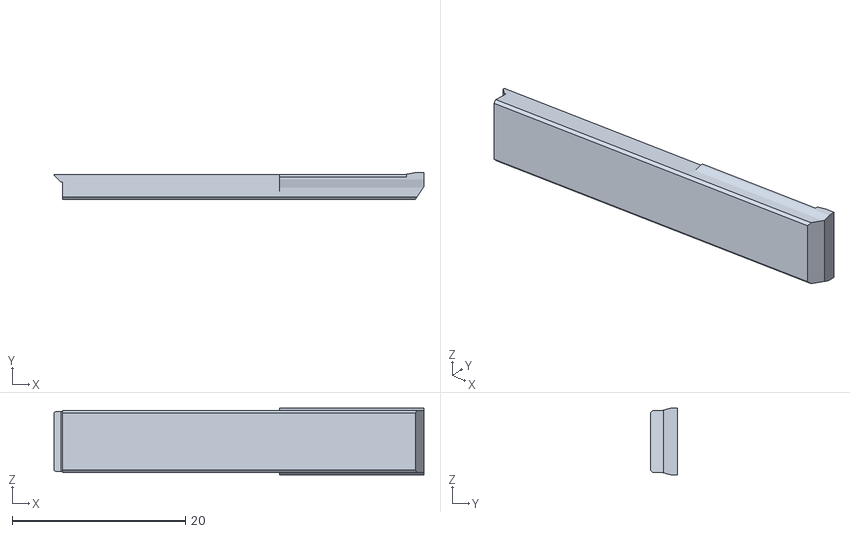
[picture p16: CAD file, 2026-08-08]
pok016/pok16-openerMasker.stl
42.7 x 3.10 x 7.68

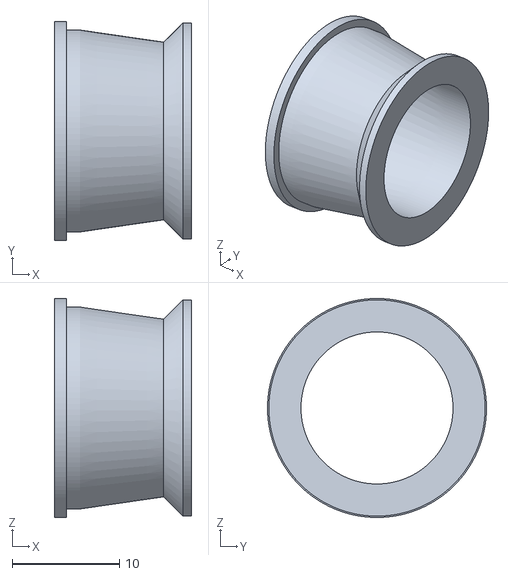
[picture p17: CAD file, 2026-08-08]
pok016/pok16-openerMotoFix.stl
12.8 x 20.5 x 20.5

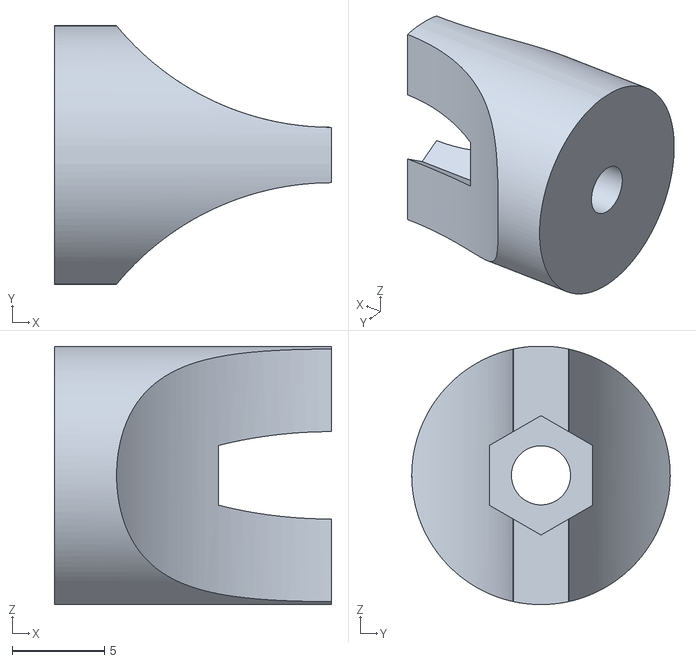
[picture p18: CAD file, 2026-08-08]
pok016/pok16-openerFixerNut.stl
15.0 x 14.0 x 14.0

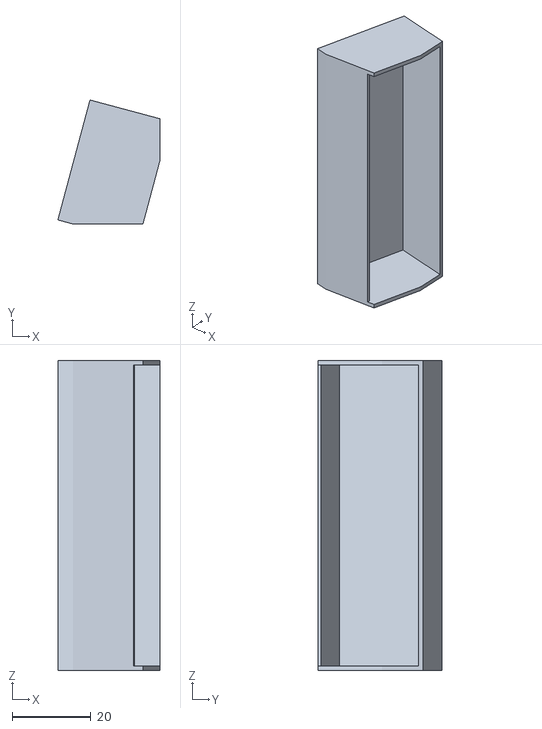
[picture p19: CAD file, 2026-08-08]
pok016/pok16-openerLid-Inset-Open.stl
26.0 x 31.6 x 78.9

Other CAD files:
pok016/pok16-openerEndstop.stl
pok016/pok16-openerRack.stl
pok016/pok16-openerCover.stl
pok016/pok16-openerGearSpacer.stl

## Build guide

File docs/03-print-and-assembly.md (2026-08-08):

# 3. Печать и механическая сборка

## 3.1. Что печатать

Из 18 файлов печатаются **16**. Два (`Lid-Insert`, `Lid-Inset-Open`) —
служебные булевы заготовки из CAD, они не детали.

Ещё нюанс: `pok016-MotoFix.stl` и `pok16-openerMotoFix.stl` — **одна и та же
деталь** (объём совпадает до сотых, 1,05 см³). Первая просто повёрнута
в удобную для печати ориентацию. Печатайте **одну** из них — ту, что
с префиксом `pok016`.

| Деталь | Кол-во | Ориентация | Поддержки |
|---|---|---|---|
| `openerRack` | 1 | зубчатой полосой вертикально | под крюком |
| `openerCover` | 1 | открытой стороной вниз | нет |
| `openerMotoBase` | 1 | площадкой мотора вниз | нет |
| `openerGuide1` | 1 | плоскостью вниз | нет |
| `openerGuide2` | 1 | плоскостью вниз | нет |
| `openerLid` | 1 | плоской стороной вниз | нет |
| `openerFixer` | 1 | основанием вниз | нет |
| `openerFixerNut` | 1 | плоскостью вниз | нет |
| `openerEndstop` | 1 | плоскостью вниз | нет |
| `pok016-MotoFix` | 1 | фланцем вниз | нет |
| `openerMotoFixSuport` | 1 | плашмя | нет |
| `openerGearSpacer` | 1 | плашмя | нет |
| `openerMasker` | 1 | плашмя | нет |
| `openerOffTool` | 1 | плашмя | нет |
| `openerMotoNut` | 1 | плашмя | нет |

### Общие настройки

- **Материал: PETG.** Обоснование — в `docs/02-bom.md`, §2.4.
- Сопло 0,4 мм, слой 0,2 мм (рейка — 0,15 мм).
- Периметров 3 (рейка и `MotoBase` — 4).
- Заполнение 25 % (рейка — 40 % gyroid).
- Обдув 50 % — PETG не любит сильный обдув, слои хуже спекаются.

### Про рейку отдельно

`openerRack` — деталь, которая передаёт всё усилие. Зубчатая полоса
всего **2,25 мм толщиной и 9 мм шириной**. Печатайте её так, чтобы
слои шли **поперёк** направления нагрузки, иначе зубья отломятся по слою.
Правильная ориентация — полосой вверх, крюк внизу на столе.

Напечатайте **две штуки**. Первая почти наверняка уйдёт на подгонку
зацепления, и лучше иметь запасную сразу.

## 3.2. Подготовка деталей

1. Снимите поддержки, зачистите первый слой канцелярским ножом.
2. **Прогоните зубья рейки** — проведите по ним металлической шестернёй
   от руки, снимите заусенцы надфилем. Зацепление должно быть без закусывания.
3. Отверстия ⌀3,3 в `Fixer` прогоните сверлом 3,3 мм — после печати они
   всегда чуть уже.
4. Если используете латунные вставки M3 — запрессуйте их паяльником
   при 220 °C, не спеша, строго вертикально.

## 3.3. Сборка узла мотора

Порядок сборки (собирайте **на столе**, до установки на окно):

1. **Наденьте `MotoFixSuport`** (шайба ⌀17,8 × 2 мм) на бобышку мотора.
2. Прикрутите мотор к площадке `MotoBase` четырьмя винтами **M3 × 12**.
   Вал должен пройти в центральное отверстие ⌀21 мм.
3. **Вкрутите `MotoFix`** — коническую втулку — с наружной стороны площадки.
   Она центрирует вал и служит подшипником скольжения.
4. Наденьте `GearSpacer` на вал (лыска шайбы совпадает с лыской вала).
5. **Насадите шестерню** m1 z18 и затяните стопорный винт **по лыске вала**.
   Не по круглой части — провернётся.
6. Проверьте: шестерня должна крутиться без биения, осевой люфт < 0,3 мм.

### Проверка зацепления — ключевой момент

Приложите рейку зубьями к шестерне и прокрутите мотор рукой.

- **Ходит туго, слышен скрип** → зазор мал. Подложите под площадку мотора
  шайбы 0,2–0,3 мм, отодвиньте ось.
- **Проскакивает, есть заметный люфт** → зазор велик. Возьмите шестерню z19.
- **Ходит плавно с еле заметным люфтом** → правильно.

По модели межосевое расстояние = **9,25 мм** от делительной линии рейки
до оси вала. При шестерне z18 (⌀18) теоретическое — 9,0 мм, то есть
конструктор заложил 0,25 мм зазора специально под FDM. Если у вас
всё село идеально с первого раза — не трогайте.

## 3.4. Сборка направляющих

1. `Guide1` — Г-образный кронштейн — прикручивается к `MotoBase`.
2. `Guide2` — прижимная планка, держит рейку в зацеплении. Ставится
   двумя винтами M3 после того, как рейка вставлена.
3. **Вставьте рейку** в канал между шестернёй и `Guide2`.
4. `Endstop` ставится сверху — он ограничивает ход рейки наружу
   и физически не даёт ей выехать из зацепления.

Прокрутите механизм рукой из края в край. Рейка должна ходить **без рывков
и без перекоса**. Если где-то закусывает — ищите причину сейчас, под нагрузкой
мотора эта же точка сломает зубья.

## 3.5. Установка на окно

> Сверлите ПВХ-профиль аккуратно: внутри есть металлическое усиление,
> и попадать саморезом нужно именно в него — иначе крепление вырвет
> при первой же нагрузке.

### Корпус привода — на раму

1. Приложите `Guide1` к раме окна как **кондуктор**: у него есть
   4 направляющих отверстия ⌀2,5 мм по сетке **31,5 × 61,2 мм**.
2. Отметьте и накерните 4 точки.
3. Просверлите ⌀3,0 мм (под саморез 4 мм по металлу усиления).
4. Прикрутите `MotoBase` саморезами **4 × 35 мм**.

### Кронштейн `Fixer` — на створку

1. Закройте окно.
2. Приложите `Fixer` к створке напротив проушины рейки.
3. Отметьте два отверстия M3, просверлите ⌀2,5 мм.
4. Прикрутите `Fixer` с подложкой `FixerNut` с обратной стороны.
5. Соедините проушину рейки с `Fixer` **винтом M4 × 25** с гайкой.
   Затягивайте так, чтобы шарнир **свободно проворачивался** —
   это шарнир, а не жёсткое соединение.

### Проверка перед подачей питания

Прокрутите привод рукой из полностью закрытого в полностью открытое:

- створка идёт плавно, без перекоса;
- рейка не выходит за `Endstop`;
- в крайних положениях нет упора «в металл»;
- шарнир M4 не подклинивает.

## 3.6. Установка концевиков

Концевики `SS-5GL` ставятся так, чтобы срабатывать **чуть раньше**
механического упора — за 2–3 мм.

- **«Закрыто»** — срабатывает, когда створка прижата, но рейка ещё не уперлась.
- **«Открыто»** — срабатывает у `Endstop`, до выхода рейки из зацепления.

Крепить проще всего на двусторонний скотч 3M VHB + капля термоклея
для фиксации. Если хочется аккуратно — под них легко добавить
кронштейн-держатель, `Endstop` для этого удобно дорабатывается.

> Можно собрать и **без концевиков** (`USE_LIMIT_SWITCHES 0` в `config.h`) —
> тогда крайние положения определяются только по току. Работать будет,
> но каждый цикл будет заканчиваться упором в механику. Для долгой
> жизни пластиковой рейки концевики лучше поставить.

## 3.7. Отсек электроники

Свободный объём под `Lid` — **21,2 × 31,6 × 78,9 мм**.

Рекомендуемая укладка «этажами» снизу вверх:

1. **MP1584** (22 × 17 мм) — внизу, ближе к вводу питания;
2. **DRV8871** (20 × 20 мм) — посередине, радиатором к стенке корпуса;
3. **ESP32-C6 SuperMini** (23 × 18 мм) — **сверху, антенной наружу**.

Антенна ESP32-C6 — это зигзагообразная дорожка на торце платы.
Её нельзя прижимать к металлу и нельзя закрывать проводами питания.
Разверните плату так, чтобы этот торец смотрел в сторону `Lid`,
то есть наружу от мотора.

**INA219** удобно приклеить на стенку рядом с вводом 12 В — он должен
стоять в разрыве плюсового провода мотора.

Провода мотора выведите через паз в `MotoBase`, скрутив их в косичку.
`Masker` закрывает этот паз снаружи.

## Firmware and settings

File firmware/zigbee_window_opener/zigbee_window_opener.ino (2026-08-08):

// ============================================================================
//  OpenWindow — Zigbee-привод открывания окна на проветривание
//  ---------------------------------------------------------------------------
//  Плата     : ESP32-C6 (ESP32-C6-DevKitC-1 или SuperMini)
//  Ядро      : arduino-esp32 3.1.0 и новее
//  Настройки : Tools → Zigbee mode      : "Zigbee ZCZR (coordinator/router)"
//              Tools → Partition Scheme : "Zigbee ZCZR 4MB with spiffs"
//              Tools → Erase All Flash  : "Enabled" (только при первой прошивке)
//  ---------------------------------------------------------------------------
//  Устройство представляется в сети как Window Covering (кластер 0x0102),
//  поэтому Home Assistant (ZHA), Zigbee2MQTT и deCONZ видят его как штору:
//  открыть / закрыть / стоп / задать позицию в процентах.
//
//  ВАЖНО про проценты. В стандарте ZCL:
//      0   = полностью ОТКРЫТО
//      100 = полностью ЗАКРЫТО
//  В Home Assistant у сущности cover наоборот (100 = открыто) — координатор
//  пересчитывает это сам, вам ничего делать не нужно.
// ============================================================================

#include "config.h"
#include <Zigbee.h>
#include <Preferences.h>
#include <Wire.h>

// ---------------------------------------------------------------------------
//  Глобальное состояние
// ---------------------------------------------------------------------------
ZigbeeWindowCovering zbCover(ZB_ENDPOINT);
Preferences prefs;

enum State  : uint8_t { ST_IDLE, ST_MOVING, ST_CALIBRATING, ST_FAULT };
enum Dir    : int8_t  { DIR_OPEN = -1, DIR_NONE = 0, DIR_CLOSE = +1 };

static State    g_state      = ST_IDLE;
static Dir      g_dir        = DIR_NONE;

static float    g_posPct     = 100.0f;              // текущая позиция, 0=открыто 100=закрыто
static uint8_t  g_targetPct  = 100;                 // куда едем
static uint32_t g_travelMs   = DEFAULT_TRAVEL_MS;   // время полного хода (калибруется)

static uint32_t g_moveStart  = 0;                   // millis() старта движения
static float    g_posAtStart = 100.0f;
static uint32_t g_lastTick   = 0;
static uint32_t g_lastReport = 0;

static uint32_t g_overCurrentSince = 0;             // для детекта защемления

// Печатать ток в Serial раз в 200 мс — включите на время подбора
// CURRENT_STALL_A (см. docs/04-electronics.md, §3.4), потом выключите.
#define DEBUG_CURRENT 0

// Запросы из Zigbee-колбэков (в самих колбэках ничего долгого делать нельзя)
static volatile bool    g_reqOpen   = false;
static volatile bool    g_reqClose  = false;
static volatile bool    g_reqStop   = false;
static volatile bool    g_reqGoto   = false;
static volatile uint8_t g_reqGotoPct = 0;

// ---------------------------------------------------------------------------
//  Светодиод состояния
// ---------------------------------------------------------------------------
static void led(uint8_t r, uint8_t g, uint8_t b) {
#ifdef RGB_BUILTIN
  rgbLedWrite(PIN_RGB_LED, r, g, b);   // если не компилируется — neopixelWrite(PIN_RGB_LED, r, g, b)
#else
  (void)r; (void)g; (void)b;
#endif
}

// ---------------------------------------------------------------------------
//  INA219 — минимальный драйвер, внешние библиотеки не нужны
// ---------------------------------------------------------------------------
#if USE_INA219
static bool g_inaOk = false;

static void inaInit() {
  Wire.begin(PIN_I2C_SDA, PIN_I2C_SCL);
  Wire.beginTransmission(INA219_ADDR);
  Wire.write(0x00);            // регистр конфигурации
  Wire.write(0x39);            // 32 В, ±320 мВ, 12 бит, непрерывное измерение
  Wire.write(0x9F);
  g_inaOk = (Wire.endTransmission() == 0);
  Serial.printf("[INA219] %s\n", g_inaOk ? "найден" : "НЕ найден — защита по току отключена");
}

// Возвращает ток мотора в амперах (по падению на шунте)
static float motorCurrent() {
  if (!g_inaOk) return 0.0f;
  Wire.beginTransmission(INA219_ADDR);
  Wire.write(0x01);                                  // регистр Shunt Voltage
  if (Wire.endTransmission(false) != 0) return 0.0f;
  if (Wire.requestFrom(INA219_ADDR, 2) != 2) return 0.0f;
  int16_t raw = (int16_t)((Wire.read() << 8) | Wire.read());
  float vShunt = raw * 10e-6f;                       // LSB = 10 мкВ
  return fabsf(vShunt / INA219_SHUNT_OHM);
}
#else
static void  inaInit() {}
static float motorCurrent() { return 0.0f; }
#endif

// ---------------------------------------------------------------------------
//  Концевики
// ---------------------------------------------------------------------------
static bool limitClosedHit() {
#if USE_LIMIT_SWITCHES
  return digitalRead(PIN_LIMIT_CLOSED) == LOW;
#else
  return false;
#endif
}

static bool limitOpenHit() {
#if USE_LIMIT_SWITCHES
  return digitalRead(PIN_LIMIT_OPEN) == LOW;
#else
  return false;
#endif
}

// ---------------------------------------------------------------------------
//  Управление мотором (DRV8871: IN1/IN2, ШИМ по одному из входов)
// ---------------------------------------------------------------------------
static void motorStop() {
  ledcWrite(PIN_MOTOR_IN1, PWM_MAX);    // оба входа в HIGH = торможение обмоткой
  ledcWrite(PIN_MOTOR_IN2, PWM_MAX);
  delay(40);
  ledcWrite(PIN_MOTOR_IN1, 0);          // затем свободный выбег
  ledcWrite(PIN_MOTOR_IN2, 0);
}

static void motorDrive(Dir dir, uint16_t duty) {
  bool closing = (dir == DIR_CLOSE);
#if MOTOR_INVERT
  closing = !closing;
#endif
  if (closing) { ledcWrite(PIN_MOTOR_IN1, duty); ledcWrite(PIN_MOTOR_IN2, 0); }
  else         { ledcWrite(PIN_MOTOR_IN1, 0);    ledcWrite(PIN_MOTOR_IN2, duty); }
}

// Скважность с плавным разгоном и торможением у цели
static uint16_t rampedDuty(uint32_t elapsedMs, float remainingPct) {
  float k = 1.0f;
  if (elapsedMs < RAMP_MS) k = (float)elapsedMs / RAMP_MS;          // разгон
  float brakePct = 100.0f * RAMP_MS / (float)g_travelMs;            // зона торможения
  if (remainingPct < brakePct && brakePct > 0.5f) {
    k = fminf(k, remainingPct / brakePct);
  }
  uint16_t duty = (uint16_t)(DUTY_MIN + (DUTY_RUN - DUTY_MIN) * k);
  return constrain(duty, DUTY_MIN, DUTY_RUN);
}

// ---------------------------------------------------------------------------
//  Сообщаем позицию координатору
// ---------------------------------------------------------------------------
static void reportPosition() {
  uint8_t p = (uint8_t)lroundf(constrain(g_posPct, 0.0f, 100.0f));
  zbCover.setLiftPercentage(p);
  zbCover.setLiftPosition((uint16_t)(p * STROKE_MM / 100));
}

// ---------------------------------------------------------------------------
//  Движение
// ---------------------------------------------------------------------------
static void stopMotion(const char *why) {
  motorStop();
  g_dir   = DIR_NONE;
  g_state = ST_IDLE;
  g_overCurrentSince = 0;
  reportPosition();
  Serial.printf("[MOVE] стоп (%s), позиция %.1f%%\n", why, g_posPct);
  led(0, 8, 0);
}

static void startMotion(uint8_t targetPct) {
  targetPct = constrain(targetPct, 0, 100);

  // Уже на месте (в пределах 1 %) — ничего не делаем
  if (fabsf(g_posPct - targetPct) < 1.0f) {
    g_posPct = targetPct;
    reportPosition();
    return;
  }

  g_targetPct  = targetPct;
  g_dir        = (targetPct > g_posPct) ? DIR_CLOSE : DIR_OPEN;
  g_posAtStart = g_posPct;
  g_moveStart  = millis();
  g_lastTick   = g_moveStart;
  g_state      = ST_MOVING;
  g_overCurrentSince = 0;

  Serial.printf("[MOVE] %.1f%% → %u%% (%s)\n", g_posPct, targetPct,
                g_dir == DIR_CLOSE ? "закрываем" : "открываем");
  led(0, 0, 20);
}

// Обновление позиции по времени + обработка концевиков, тока, достижения цели
static void updateMotion() {
  uint32_t now = millis();
  uint32_t dt  = now - g_lastTick;
  g_lastTick   = now;

  // 1. Интегрируем позицию по времени
  float dPct = 100.0f * (float)dt / (float)g_travelMs;
  g_posPct  += (g_dir == DIR_CLOSE) ? dPct : -dPct;
  g_posPct   = constrain(g_posPct, 0.0f, 100.0f);

  // 2. Концевики — они всегда важнее расчёта по времени
  if (g_dir == DIR_CLOSE && limitClosedHit()) { g_posPct = 100.0f; stopMotion("концевик «закрыто»"); return; }
  if (g_dir == DIR_OPEN  && limitOpenHit())   { g_posPct = 0.0f;   stopMotion("концевик «открыто»");  return; }

  // 3. Защита от защемления
  uint32_t elapsed = now - g_moveStart;
  if (elapsed > INRUSH_IGNORE_MS) {
    float i = motorCurrent();
    if (i > CURRENT_STALL_A) {
      if (g_overCurrentSince == 0) g_overCurrentSince = now;
      if (now - g_overCurrentSince > STALL_CONFIRM_MS) {
        Serial.printf("[SAFE] перегрузка %.2f А — препятствие!\n", i);
        // отъезжаем назад, чтобы освободить то, что зажали
        Dir back = (g_dir == DIR_CLOSE) ? DIR_OPEN : DIR_CLOSE;
        motorStop();
        delay(150);
        motorDrive(back, DUTY_RUN);
        delay(BACKOFF_MS);
        motorStop();
        g_posPct += (back == DIR_CLOSE ? 1 : -1) * 100.0f * BACKOFF_MS / g_travelMs;
        g_posPct  = constrain(g_posPct, 0.0f, 100.0f);
        g_state   = ST_FAULT;
        g_dir     = DIR_NONE;
        reportPosition();
        led(30, 0, 0);
        return;
      }
    } else {
      g_overCurrentSince = 0;
    }
  }

  // 4. Аварийный таймаут
  if (elapsed > (uint32_t)(g_travelMs * MAX_TRAVEL_FACTOR)) {
    stopMotion("таймаут");
    return;
  }

  // 5. Достигли цели
  bool reached = (g_dir == DIR_CLOSE) ? (g_posPct >= g_targetPct) : (g_posPct <= g_targetPct);
  if (reached) {
    // В крайние положения доезжаем до упора/концевика, а не по таймеру
    if ((g_targetPct >= 100 && (limitClosedHit() || !USE_LIMIT_SWITCHES)) ||
        (g_targetPct <= 0   && (limitOpenHit()   || !USE_LIMIT_SWITCHES)) ||
        (g_targetPct > 0 && g_targetPct < 100)) {
      g_posPct = g_targetPct;
      stopMotion("цель достигнута");
      return;
    }
  }

  // 6. Крутим мотор с нужной скважностью
  float remaining = fabsf(g_targetPct - g_posPct);
  motorDrive(g_dir, rampedDuty(elapsed, remaining));

  // 7. Периодический отчёт в сеть
  if (now - g_lastReport > REPORT_INTERVAL_MS) {
    g_lastReport = now;
    reportPosition();
  }
}

// ---------------------------------------------------------------------------
//  Калибровка: полностью закрыть, затем полностью открыть и замерить время
// ---------------------------------------------------------------------------
static void calibrate() {
  Serial.println("[CAL] калибровка началась");
  led(20, 12, 0);
  g_state = ST_CALIBRATING;

  const uint32_t HARD_LIMIT = 30000;   // абсолютный предел одного прохода, мс

  // Фаза 1 — в положение «закрыто»
  uint32_t t0 = millis();
  motorDrive(DIR_CLOSE, DUTY_RUN);
  while (millis() - t0 < HARD_LIMIT) {
    if (limitClosedHit()) break;
    if (millis() - t0 > INRUSH_IGNORE_MS && motorCurrent() > CURRENT_STALL_A) break;
    delay(5);
  }
  motorStop();
  delay(400);

  // Фаза 2 — в положение «открыто», засекаем время
  t0 = millis();
  motorDrive(DIR_OPEN, DUTY_RUN);
  while (millis() - t0 < HARD_LIMIT) {
    if (limitOpenHit()) break;
    if (millis() - t0 > INRUSH_IGNORE_MS && motorCurrent() > CURRENT_STALL_A) break;
    delay(5);
  }
  uint32_t measured = millis() - t0;
  motorStop();

  if (measured > 1000) {
    g_travelMs = measured;
    prefs.begin("openwindow", false);
    prefs.putULong("travelMs", g_travelMs);
    prefs.end();
    Serial.printf("[CAL] полный ход = %lu мс, сохранено\n", (unsigned long)g_travelMs);
  } else {
    Serial.println("[CAL] не удалось измерить — оставляем прежнее значение");
  }

  g_posPct = 0.0f;             // после калибровки окно открыто
  g_state  = ST_IDLE;
  reportPosition();
  led(0, 8, 0);
}

// ---------------------------------------------------------------------------
//  Zigbee-колбэки: только выставляют флаги
// ---------------------------------------------------------------------------
static void cbOpen()                  { g_reqOpen  = true; }
static void cbClose()                 { g_reqClose = true; }
static void cbStop()                  { g_reqStop  = true; }
static void cbGoToLift(uint8_t pct)   { g_reqGotoPct = pct; g_reqGoto = true; }

// ---------------------------------------------------------------------------
//  Кнопка BOOT: короткое нажатие — открыть/закрыть,
//               3 с — калибровка, 10 с — сброс к заводским (выход из сети)
// ---------------------------------------------------------------------------
static void handleButton() {
  static uint32_t pressedAt = 0;
  static bool     wasDown   = false;
  bool down = (digitalRead(PIN_BUTTON) == LOW);

  if (down && !wasDown) { pressedAt = millis(); }

  if (!down && wasDown) {
    uint32_t held = millis() - pressedAt;
    if (held > 10000) {
      Serial.println("[BTN] сброс к заводским настройкам, выходим из сети…");
      led(30, 0, 30);
      delay(300);
      Zigbee.factoryReset();
    } else if (held > 3000) {
      calibrate();
    } else if (held > 40) {
      if (g_state == ST_MOVING) stopMotion("кнопка");
      else                      startMotion(g_posPct > 50 ? 0 : 100);
    }
  }
  wasDown = down;
}

// ---------------------------------------------------------------------------
//  setup()
// ---------------------------------------------------------------------------
void setup() {
  Serial.begin(115200);
  delay(300);
  Serial.println("\n=== OpenWindow — Zigbee window opener ===");

  // --- ШИМ на мотор ---
  ledcAttach(PIN_MOTOR_IN1, PWM_FREQ_HZ, PWM_RESOLUTION);
  ledcAttach(PIN_MOTOR_IN2, PWM_FREQ_HZ, PWM_RESOLUTION);
  motorStop();

  // --- Входы ---
  pinMode(PIN_LIMIT_CLOSED, INPUT_PULLUP);
  pinMode(PIN_LIMIT_OPEN,   INPUT_PULLUP);
  pinMode(PIN_BUTTON,       INPUT_PULLUP);

  inaInit();

  // --- Восстанавливаем калибровку и позицию ---
  prefs.begin("openwindow", true);
  g_travelMs = prefs.getULong("travelMs", DEFAULT_TRAVEL_MS);
  g_posPct   = prefs.getUChar("pos", 100);
  prefs.end();
  Serial.printf("[NVS] полный ход %lu мс, позиция %.0f%%\n",
                (unsigned long)g_travelMs, g_posPct);

  // --- Zigbee-эндпоинт ---
  zbCover.setManufacturerAndModel(ZB_MANUFACTURER, ZB_MODEL);
  zbCover.setCoveringType(AWNING);                 // ближайший тип для откидного окна
  zbCover.setConfigStatus(
      /*operational*/            true,
      /*online*/                 true,
      /*commands_reversed*/      false,
      /*lift_closed_loop*/       true,
      /*tilt_closed_loop*/       false,
      /*lift_encoder_controlled*/false,
      /*tilt_encoder_controlled*/false);
  zbCover.setMode(/*motor_reversed*/false, /*calibration*/false,
                  /*maintenance*/false, /*leds_on*/false);
  zbCover.setLimits(/*open lift*/0, /*closed lift*/STROKE_MM, /*open tilt*/0, /*closed tilt*/0);

  zbCover.onOpen(cbOpen);
  zbCover.onClose(cbClose);
  zbCover.onStop(cbStop);
  zbCover.onGoToLiftPercentage(cbGoToLift);

  Zigbee.addEndpoint(&zbCover);

  Serial.println("[ZB] запуск стека…");
  if (!Zigbee.begin(ZB_ROLE)) {
    Serial.println("[ZB] стек не стартовал — перезагрузка");
    delay(1000);
    ESP.restart();
  }

  Serial.print("[ZB] подключение к сети");
  while (!Zigbee.connected()) {
    Serial.print('.');
    led(20, 20, 0);
    delay(150);
    led(0, 0, 0);
    delay(150);
  }
  Serial.println(" готово");
  led(0, 8, 0);

  reportPosition();
}

// ---------------------------------------------------------------------------
//  loop()
// ---------------------------------------------------------------------------
void loop() {
  handleButton();

#if DEBUG_CURRENT
  static uint32_t lastDbg = 0;
  if (millis() - lastDbg > 200) {
    lastDbg = millis();
    Serial.printf("I = %.2f A  pos = %.1f%%\n", motorCurrent(), g_posPct);
  }
#endif

  // Команды из сети
  if (g_reqStop)  { g_reqStop = false; if (g_state == ST_MOVING) stopMotion("команда STOP"); }
  if (g_reqOpen)  { g_reqOpen = false;  g_state = ST_IDLE; startMotion(0);   }
  if (g_reqClose) { g_reqClose = false; g_state = ST_IDLE; startMotion(100); }
  if (g_reqGoto)  { g_reqGoto = false;  g_state = ST_IDLE; startMotion(g_reqGotoPct); }

  if (g_state == ST_MOVING) {
    updateMotion();
  } else {
    // Сохраняем позицию в NVS не чаще раза в 5 с и только когда стоим
    static uint32_t lastSave = 0;
    static uint8_t  lastSaved = 255;
    uint8_t p = (uint8_t)lroundf(g_posPct);
    if (p != lastSaved && millis() - lastSave > 5000) {
      prefs.begin("openwindow", false);
      prefs.putUChar("pos", p);
      prefs.end();
      lastSaved = p;
      lastSave  = millis();
    }
  }

  delay(5);
}

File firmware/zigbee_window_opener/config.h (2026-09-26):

// ============================================================================
//  OpenWindow — конфигурация железа и поведения
//  Всё, что вам нужно править под свою сборку, находится в этом файле.
// ============================================================================
#pragma once

// ---------------------------------------------------------------------------
//  1. РАСПИНОВКА (ESP32-C6-DevKitC-1 / ESP32-C6 SuperMini)
// ---------------------------------------------------------------------------
//  Не занимайте GPIO12/13 — это USB. GPIO4/5/8/9/15 — strapping-пины,
//  их можно использовать, но не как выходы, тянущие уровень при старте.

#define PIN_MOTOR_IN1      2    // DRV8871 IN1  (ШИМ)
#define PIN_MOTOR_IN2      3    // DRV8871 IN2  (ШИМ)

// Все пины ниже выведены и на DevKitC-1, и на SuperMini
#define PIN_LIMIT_CLOSED  18    // концевик «окно закрыто»   (в GND, INPUT_PULLUP)
#define PIN_LIMIT_OPEN    19    // концевик «окно открыто»   (в GND, INPUT_PULLUP)

#define PIN_I2C_SDA        6    // INA219 (датчик тока) и опциональный SHT4x
#define PIN_I2C_SCL        7

#define PIN_BUTTON         9    // кнопка BOOT на плате
#define PIN_RGB_LED        8    // встроенный адресный светодиод DevKitC-1

// ---------------------------------------------------------------------------
//  2. МЕХАНИКА (значения измерены по STL из папки pok016/)
// ---------------------------------------------------------------------------
#define STROKE_MM              100   // рабочий ход рейки, мм (зубчатая часть 112 мм)
#define DEFAULT_TRAVEL_MS     9000   // ход из края в край до калибровки, мс
#define MAX_TRAVEL_FACTOR      1.4f  // аварийный стоп при времени > калибровка × этого

// ---------------------------------------------------------------------------
//  3. МОТОР И ШИМ
// ---------------------------------------------------------------------------
#define PWM_FREQ_HZ        20000   // 20 кГц — выше слышимого диапазона
#define PWM_RESOLUTION        10   // 10 бит → значения 0..1023
#define PWM_MAX             1023

#define DUTY_RUN             900   // рабочая скважность (≈88 % от 12 В)
#define DUTY_MIN             350   // минимум, при котором мотор ещё крутится
#define RAMP_MS              350   // плавный разгон/торможение, мс

// Инвертировать направление, если окно едет «наоборот»
#define MOTOR_INVERT           0   // 0 или 1

// ---------------------------------------------------------------------------
//  4. ЗАЩИТА ОТ ЗАЩЕМЛЕНИЯ (по току, INA219)
// ---------------------------------------------------------------------------
#define USE_INA219             1   // 0 — собрать без датчика тока
#define INA219_ADDR         0x40
#define INA219_SHUNT_OHM    0.1f   // шунт на типовом модуле GY-219

#define CURRENT_STALL_A     1.20f  // порог «упёрлись», А — подберите по факту!
#define STALL_CONFIRM_MS      250  // столько мс подряд ток должен быть выше порога
#define INRUSH_IGNORE_MS      600  // игнорировать пусковой ток первые N мс
#define BACKOFF_MS            700  // на сколько отъехать назад после защемления

// ---------------------------------------------------------------------------
//  5. КОНЦЕВИКИ
// ---------------------------------------------------------------------------
#define USE_LIMIT_SWITCHES     1   // 0 — работать только по времени и току
#define DEBOUNCE_MS           25

// ---------------------------------------------------------------------------
//  6. ZIGBEE
// ---------------------------------------------------------------------------
#define ZB_ENDPOINT           10
#define ZB_MANUFACTURER  "DIY"
#define ZB_MODEL         "OpenWindow-pok16"

// Роль: ROUTER — устройство постоянно запитано и ретранслирует сеть.
// Если питаете от аккумулятора — поменяйте на ZIGBEE_END_DEVICE.
#define ZB_ROLE          ZIGBEE_ROUTER

#define REPORT_INTERVAL_MS   500   // как часто слать позицию во время движения

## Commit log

2026-08-08 Add Zigbee window opener: mockup analysis, docs, firmware
    Reverse-engineered the pok016 STL set (rack & pinion window opener) by
    direct mesh measurement and built a complete Zigbee IoT project around it.
    Mockup analysis (tools/ scripts, reproducible):
    - identified rack & pinion mechanism with L-shaped toothed rack
    - rack: module 1, 3.142 mm pitch, 9 mm face width, ~112 mm toothed travel
    - pinion needed: m1 z18, PD 18 mm, 9.25 mm centre distance (not in file set)
    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
2026-08-31 Add getting-started roadmap
    Separates the two independent tracks (Zigbee hub infrastructure vs the
    window opener itself), which is the main source of confusion when
    starting. Adds an ordered plan with a verification checkpoint after each
    step, a Zigbee-vs-WiFi decision guide, hub hardware options, and a
    staged shopping list.
    Claude-Session: https://claude.ai/code/session_01HsG5RExXMKAwvA8howgHWz
2026-09-26 Move limit switches to GPIO18/19, fix switch contact in wiring table
    GPIO10/11 are not broken out on ESP32-C6 SuperMini boards; GPIO18/19
    exist on both SuperMini and DevKitC-1, so the same firmware works on
    either board.
    The wiring table said to use the NC contact, but the firmware treats
    LOW as "limit reached", so the switch must be wired via its NO contact.
    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
    [config.h]
